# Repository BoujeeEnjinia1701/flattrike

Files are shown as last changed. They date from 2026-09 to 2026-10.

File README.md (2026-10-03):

# FlatTrike

     

**Area:** Mobility and Logistics · **TRL:** 3 of 9 (proof of concept on paper) · **Value-engineering target:** about $800 USD (estimated parts cost $736) · **Difficulty:** 3 of 5

Bolt-together cargo tricycle whose frame is cut from flat sheet steel by any laser or waterjet shop, uses standard bicycle parts, and ships flat.

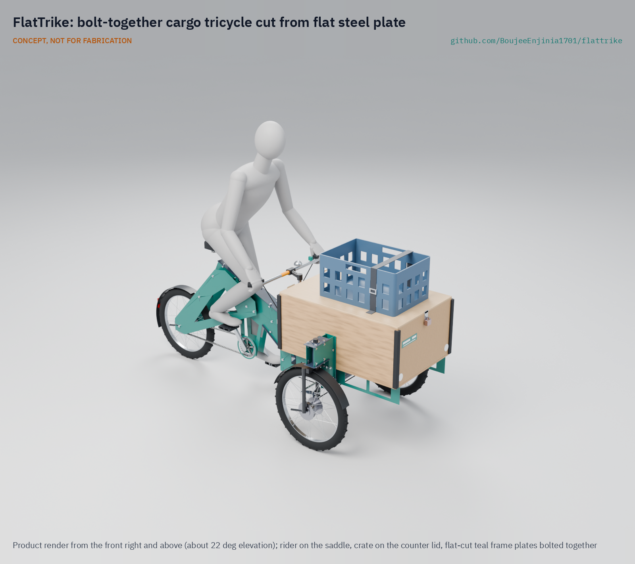
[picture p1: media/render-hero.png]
FlatTrike: bolt-together cargo tricycle cut from flat steel plate, product render


[Exploded render](media/render-exploded.png) · [Detail render](media/render-detail.png) · [Interactive 3D model](media/viewer.html) · [Concept blueprint (PDF)](media/concept-blueprint.pdf) · [General arrangement (PDF)](cad/drawings/FTK-DWG-001.pdf) · [Sizing note](docs/04-calcs/01-sizing.md) · [Prototype build plan](docs/05-build-plan.md) · [Design decisions](docs/06-design-decisions.md) · [Review note](docs/REVIEW.md)

## Concept rationale

Cargo tricycles fail their owners in two ways: cheap workshop builds flex, crack and weigh too much, and good imported ones cost too much to buy or repair. Precision is what separates them, and in a tubular frame precision comes from jigs and skilled welding. FlatTrike moves that precision into the cutting file. Every steel part is a flat 3 mm plate that any laser or waterjet shop can cut from open DXF files, tabs and slots make the plates locate one another, and bolts with all-metal locknuts replace welds. The moving parts (wheels, drum hubs, forks, headsets, chain and cranks) are standard bicycle parts sold in regional markets.

Keeping the design open and garage-buildable is the point, not a side effect. A frame that anyone can re-cut is a frame that a vendor in Pune or Nairobi can repair one plate at a time, at a local shop, without waiting for a proprietary spare. A prototype for about $800 in parts lets a cooperative, a university workshop or a single mechanic build and test one before anyone commits to a batch.

## Burning platform

About two billion people, more than 61 % of the world's employed population, work in the informal economy, rising to 85.8 % of employment in Africa ([ILO, 2018](https://www.ilo.org/resource/news/more-60-cent-world%E2%80%99s-employed-population-are-informal-economy)). Street vending and small-scale carrying are a large part of that work, and they run on human-powered vehicles. In India alone, the government's PM SVANidhi microcredit scheme had lent to more than 68 lakh (6.8 million) street vendors by July 2025 and is being extended to 2030 ([Press Information Bureau, 2025](https://www.pib.gov.in/PressReleasePage.aspx?PRID=2161157&reg=48&lang=2)).

The vehicles these workers use have barely changed. ITDP found that the traditional Indian cycle rickshaw weighs about 80 kg, has a single high gear, and has a wooden passenger structure that must be replaced every two to three years ([ITDP, 2006](https://itdp.org/2006/07/01/rickshaws-in-the-new-millennium/)). Every extra kilogram and every repair comes out of an income measured in trips per day, so a lighter, longer-lived and locally repairable cargo trike is worth more to these users than almost any other tool.

## Where it could be used

### By industry

| Industry | Use |
| --- | --- |
| Street vending and food retail | Mobile stall with a lockable box whose lid is a counter |
| Last-mile parcel and grocery delivery | Pedal or assisted delivery in dense districts and narrow lanes |
| Recycling and waste collection | Door-to-door collection of recyclables by informal and cooperative pickers |
| Water and gas cylinder distribution | Short, heavy delivery rounds from depot to households and shops |
| Agriculture and markets | Moving produce from farm gate or wholesale market to retail pitches |
| Municipal and campus services | Park, street-cleaning and maintenance crews carrying tools and supplies |

### By country or region

| Country or region | Why it matters there |
| --- | --- |
| India | More than 6.8 million street vendors have borrowed under PM SVANidhi ([PIB, 2025](https://www.pib.gov.in/PressReleasePage.aspx?PRID=2161157&reg=48&lang=2)); loading rickshaws and *thelas* are everywhere, and laser shops are common in industrial estates |
| Sub-Saharan Africa (for example Kenya and Nigeria) | 85.8 % of employment in Africa is informal ([ILO, 2018](https://www.ilo.org/resource/news/more-60-cent-world%E2%80%99s-employed-population-are-informal-economy)); goods move by handcart and bicycle on rough roads, where local repair matters most |
| Southeast and South Asia (for example Bangladesh and Indonesia) | 68.2 % of employment in Asia and the Pacific is informal ([ILO, 2018](https://www.ilo.org/resource/news/more-60-cent-world%E2%80%99s-employed-population-are-informal-economy)); cycle rickshaws and vending tricycles are a mainstay of city trade |
| The Americas (for example Mexico and Peru) | 40.0 % of employment in the Americas is informal ([ILO, 2018](https://www.ilo.org/resource/news/more-60-cent-world%E2%80%99s-employed-population-are-informal-economy)); a frame cut from open files suits small vendors and cooperatives in that informal economy |
| United States (New York City) | The city ran a commercial cargo bicycle pilot with delivery firms and published an evaluation ([NYC DOT](https://www.nyc.gov/html/dot/downloads/pdf/commercial-cargo-bicycle-pilot-evaluation-report.pdf)); an open, repairable frame suits small operators and community delivery schemes |

## What sparked the idea

The starting point was the OX, a flat-pack truck that Gordon Murray, the designer behind McLaren's road cars, developed for the Global Vehicle Trust, which the British philanthropist Torquil Norman founded to develop cost-effective transport for the developing world. TechCrunch reported in 2016 that six OX trucks pack into one shipping crate in flat-pack form and that a trained team of three can unpack and assemble one in about 12 hours ([TechCrunch, 2016](https://techcrunch.com/?p=1393387)). FlatTrike takes the same idea one scale down and one step further: instead of shipping a factory kit, it ships the files, so the flat parts can be cut in the city where the trike will work and re-cut there when one breaks.

## Problem

Street vendors and micro-logistics operators in emerging markets need durable cargo tricycles, but imported units are expensive and hard to repair, and cheap local workshop tricycles are heavy, flexible and short-lived.

## Concept

Bolt-together cargo tricycle whose frame is cut from flat sheet steel by any laser or waterjet shop, uses standard bicycle parts, and ships flat. The concept is a front loader: two 20 in front wheels, each steering in a standard bicycle fork linked by a tie rod (Ackermann steering), carry a fixed, lockable plywood box, and the rider sits over a standard 20 in rear wheel with a 3-speed drum brake hub. It is rated for 148 kg of cargo with a rider up to 80 kg, or 138 kg with a rider up to 90 kg, weighs 71.7 kg empty, turns in 5.64 m with a lock stop at each front wheel, and the pedal-only prototype costs $728 in parts. The TRL 3 calculations (FTK-CAL-001) show that unassisted hill climbing is not yet met, the production cost estimate (about $466) is over its $300 value-engineering target, and that making the design buildable added mass, so the cargo rating was trimmed by 2 kg to stay inside the 300 kg class (decided 2026-10-02); see the [design decisions register](docs/06-design-decisions.md) and the [review note](docs/REVIEW.md).

Full design precis: [docs/02-concept.md](docs/02-concept.md)

## Key components

- 37 laser-cut 3 mm steel plates: closed-box spine, rear stays, front bed, two knuckle posts and their steering lock stops, nested on one standard sheet
- Tab-and-slot joints and cut spacer washers with 97 M8 class 8.8 bolts and all-metal locknuts held in windows in the plates (no welding)
- Ackermann steering: central steering column in a 200 mm head tube, two 20 in straight-leg forks on their own 1 1/8 in headsets, each fitted turned round so the wheel trails its steering axis by 35 mm (decided 2026-10-03), tie rod and drag link
- 20 in wheels (3) with drum brakes; 3-speed hub at the rear
- Standard bicycle drivetrain, seat and handlebar
- Lockable plywood cargo box with a counter lid
- Optional electric assist on a SwapCell pack (route C; not in the prototype budget)

The working bill of materials is in [bom/bom.csv](bom/bom.csv).

## Building the prototype

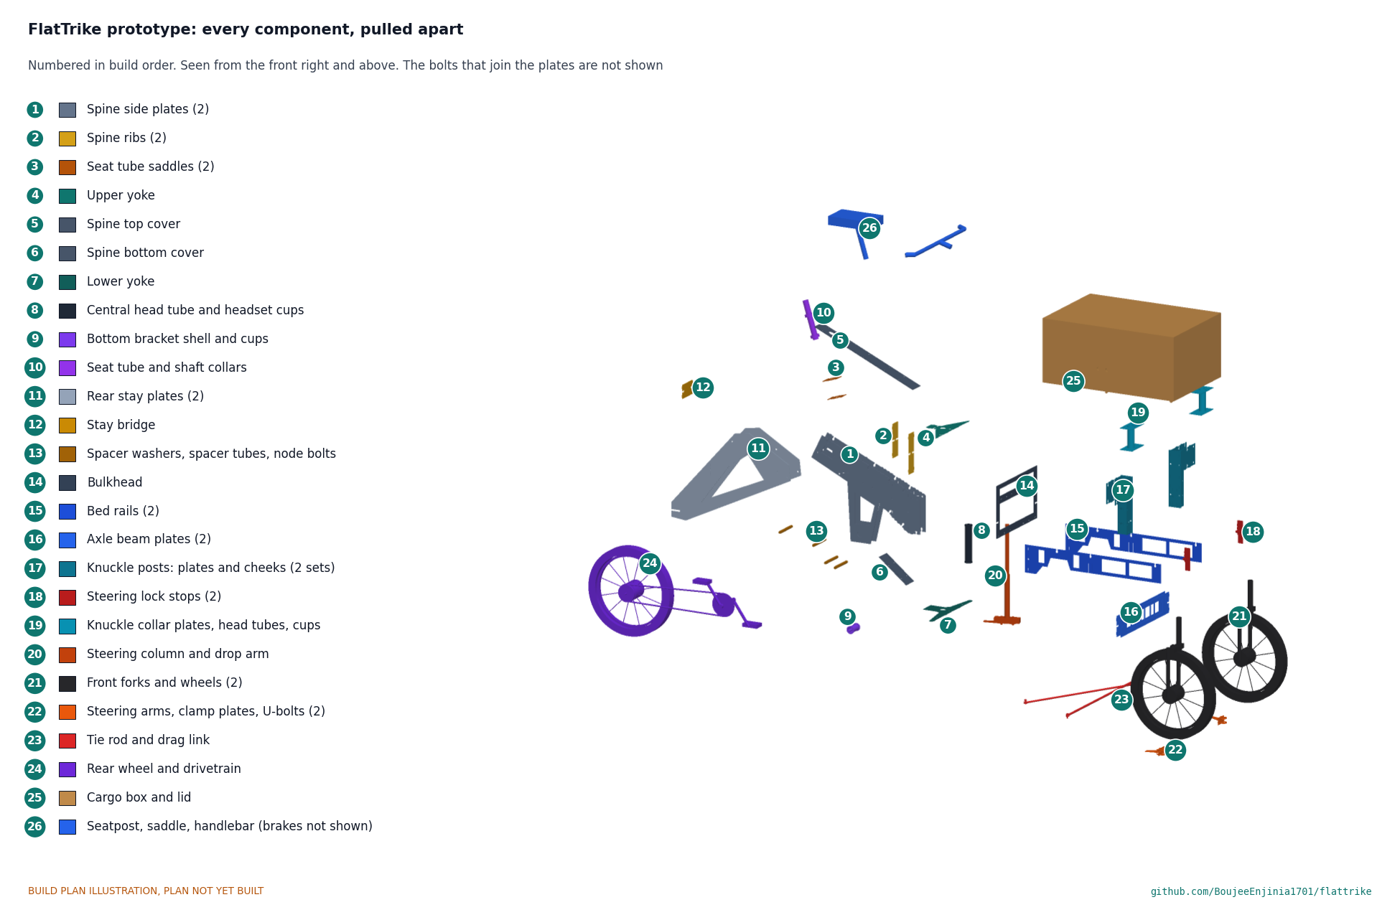
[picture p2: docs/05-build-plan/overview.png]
FlatTrike prototype: every component pulled apart and numbered in build order


The [prototype build plan](docs/05-build-plan.md) (FTK-BLD-001) shows, in pictures, how to make each of the 26 groups of parts and put them together in 21 steps; nothing has been built yet. Every frame part is a 3 mm plate cut by a laser or waterjet shop, joined by tabs in slots and M8 bolts whose locknuts sit in windows in the plates; the rest is bought bicycle parts, a cut-down fork for the steering column, three tube lengths and a plywood box. Writing the plan made the design buildable: the joints, stay bolts, dropouts, head tube clamping, steering linkage, steering arms and knuckle posts were redesigned (FTK-DDR-003, open for Amish's review), and the open decisions this raised are in the [design decisions register](docs/06-design-decisions.md). Every picture is drawn from the model, which checks that no two parts overlap, every part is fixed, and the steering turns lock to lock without touching the frame.

## Safety

> **Safety:** The frame's strength and fatigue life are unverified. Frames must be load-tested to twice the rated payload before use on public roads. Cut plate edges must be deburred, and the empty trike can tip in brisk turns, so riders must keep to 6 km/h in full-lock turns when empty. See the safety section of the [design precis](docs/02-concept.md).

## Repository layout

| Folder | Contents |
| --- | --- |
| `docs/` | Problem, concept, requirements, calculations, prototype build plan and design decisions |
| `cad/src/` | build123d Python source, the source of truth for all geometry |
| `cad/step/`, `cad/stl/` | Exported models for FreeCAD, other CAD tools and printing |
| `cad/drawings/` | 2D sketches and dimensioned drawings |
| `bom/` | Bill of materials |
| `electronics/` | KiCad schematics and PCB layouts |
| `firmware/` | Microcontroller code |
| `media/` | Renders, perspectives and photos |
| `build-log/` | Dated prototyping notes |

## Documentation

Controlled documents follow the portfolio [documentation standard](.kit/STANDARDS.md). Each carries a document ID (FTK-PRC-001 for the precis), a version and a revision history. Branded PDFs are built with `python .kit/render.py` and attached to GitHub Releases when a document is tagged, for example `FTK-PRC-001/v1.0`.

## Credits

Designed by Amish Chadha. See [CONTRIBUTORS.md](CONTRIBUTORS.md) for roles. To cite this design, use [CITATION.cff](CITATION.cff) (GitHub shows it as "Cite this repository").

AI assistance (Claude) was used to accelerate concept renders, prototype documentation and first-pass sizing calculations. Design direction and all decisions are Amish Chadha's, recorded in this repository's decision records (`docs/decisions/`).

## Licenses

- **Hardware** (CAD, drawings, BOM, electronics): [CERN-OHL-S v2](LICENSE)
- **Software** (firmware, scripts, notebooks): [MIT](LICENSE-SOFTWARE)

A project of the [Design Molecule](https://designmolecule.com) lab.

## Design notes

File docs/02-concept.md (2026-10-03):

---
doc_id: FTK-PRC-001
title: FlatTrike design precis
project: FlatTrike
doc_type: Design precis
version: "0.9"
status: Draft
date: '2026-10-03'
author: Amish Chadha
license: CERN-OHL-S-2.0
revisions:
- version: "0.1"
  date: '2026-09-24'
  author: Amish Chadha
  change: Initial scaffold
- version: "0.2"
  date: '2026-09-25'
  author: Amish Chadha
  change: Populate to TRL 2 (layout, components, first-order numbers, safety, media)
- version: "0.3"
  date: '2026-09-25'
  author: Amish Chadha
  change: TRL 3. Record decisions (FTK-DDR-001); closed-box spine, fork crown plates, wider stay strips, seat forward; numbers replaced with FTK-CAL-001 values
- version: "0.4"
  date: '2026-09-25'
  author: Amish Chadha
  change: Recommendations accepted by Amish (DDR-002)
- version: "0.5"
  date: '2026-10-01'
  author: Amish Chadha
  change: Design made constructable (FTK-DDR-003); key numbers from FTK-CAL-001 v0.3; build plan FTK-BLD-001
- version: "0.6"
  date: '2026-10-01'
  author: Amish Chadha
  change: Budget treated as a value-engineering target
- version: "0.7"
  date: '2026-10-02'
  author: Amish Chadha
  change: "Decisions of 2026-10-02: design for construction accepted; rating 148 and 138 kg, R8 72 kg, R14 60 min for knuckle post plates; steering lock stops and geometry study before the first ride; partner selection rule"
- version: "0.8"
  date: '2026-10-02'
  author: Amish Chadha
  change: "Key numbers from FTK-CAL-001 v0.6 with the 2026-10-02 decisions carried into the model: lock stops added (37 plates), 71.7 kg empty, 299.7 kg gross, turning circle 5.64 m through the built linkage, $728"
- version: "0.9"
  date: '2026-10-03'
  author: Amish Chadha
  change: "Knuckle forks turned round to trail (35 mm mechanical trail, no caster), decided by Amish 2026-10-03; key numbers from FTK-CAL-001 v0.7: wheelbase 1.415 m, turning circle 5.52 m, 71.6 kg empty, $736"
---

# FlatTrike design precis

FlatTrike is a front-loading cargo tricycle whose whole steel structure is a kit of 37 flat 3 mm plates, cut by any laser or waterjet shop from open files and bolted together through tabs, slots and spacer washers with no welding or bending. Two 20 in front wheels, each turning in a standard bicycle fork on its own headset, carry a fixed, lockable plywood cargo box; a tie rod links them in Ackermann geometry, and the rider sits over a standard 20 in rear wheel with a 3-speed drum brake hub. The TRL 3 calculations (FTK-CAL-001 v0.6, on the constructable design of FTK-DDR-003 with the decisions of 2026-10-02) show that the trike weighs 71.7 kg empty, carries 148 kg of cargo and an 80 kg rider (or 138 kg and a 90 kg rider) at 299.7 kg gross, resists tipping to 0.41 g loaded and 0.24 g with the rider only at any steering angle, turns in 5.64 m, cruises at 7.6 km/h on the flat on 110 W, nests on one standard sheet, packs into 0.31 m³ and costs an estimated $728 in prototype parts against the $800 value-engineering target (USD 72 under). One requirement is not met: a loaded 5 % hill needs 239 W at the pedals without assist (R13). The production estimate is about $466 against the $300 value-engineering target, USD 166 over (R18). The empty mass is only 0.3 kg under its 72 kg limit, and the final load label is set from the weighed trike. The [prototype build plan](05-build-plan.md) shows how every part is made and fitted.

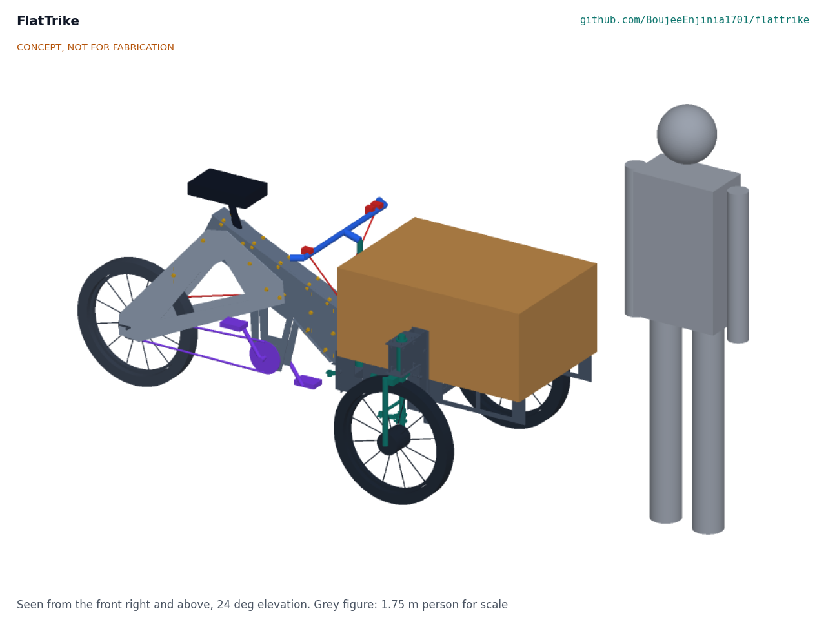
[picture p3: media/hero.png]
Hero render


*Figure 1. FlatTrike TRL 3 model with a 1.75 m person for scale. Every grey and dark steel part is a flat plate; wheels, forks, headsets, drivetrain, seat and bars are standard bicycle parts.*

## How it works

1. **Cut.** A laser or waterjet shop cuts 37 plates and 78 spacer washers from one 1,250 x 2,500 x 3 mm mild steel sheet using open DXF files, with the small plates nested in the windows of the large ones. Tabs, slots and bolt holes are cut in the same pass, so hole positions are as accurate as the cutter.
2. **Assemble.** The two spine side plates (item 1) are closed into a box beam by a top and a bottom cover plate held in slots, three ribs and cross-bolts. The box runs from the seat node to the head tube and has a drop lobe that clamps the bottom bracket shell. The rear stay plates (item 2) bolt to the outside of the spine through stacks of cut spacer washers at two nodes and carry the rear dropouts. The front bed (item 3) is a second bolted assembly: two yoke plates, a bulkhead, two rails, a twin-plate axle beam, and at each end of the beam a closed knuckle post of two transverse plates and two cheeks. No jig is needed because the plates locate one another.
3. **Fix the bed.** A 200 mm steel head tube (item 5) stands between two yoke plates at the front of the spine; each pressed headset cup passes through a yoke and clamps it to the tube's end. The yokes tab into the spine and into the bed's bulkhead, so the bed and box are fixed to the frame (FTK-DDR-003).
4. **Steer.** The handlebar (item 11) turns a steering column, a bought threaded fork cut off at its crown, in a standard 1 1/8 in threaded headset inside the head tube. A drop arm bolted under the crown, parallel to the left steering arm, drives a drag link to that arm, and a tie rod links both steering arms. Each front wheel sits in a bought 20 in fork that turns on its own headset in a 120 mm knuckle head tube, clamped above the tyre between two collar plates on the knuckle post. The fork's straight legs are offset 30 to 40 mm from its steerer, and it is fitted turned round so the wheel trails the steering axis by that offset (35 mm in the model): the tyre's side force then turns the steering back toward straight ahead. The steering arms clamp to the inboard fork legs below the knuckle posts and point at the rear axle centre, so the wheels follow Ackermann geometry.
5. **Ride.** A standard bottom bracket and cranks (item 8) drive the 20 in rear wheel (item 7) through a 32/24 chain and a 3-speed hub with a built-in drum brake. The chain runs at a 44 mm chain line in the gap between the right spine plate and the right stay plate.
6. **Stop and park.** Drum brakes in all three hubs (items 6 and 7) are sealed from rain and dust. A lever lock (item 12) holds the front pair when the trike is parked on a slope.
7. **Sell.** The plywood box (item 9) holds 151 L, locks, and has a hinged lid at 0.84 m that doubles as a counter. Its floor sits at 0.47 m so the steered tyres pass beneath it.

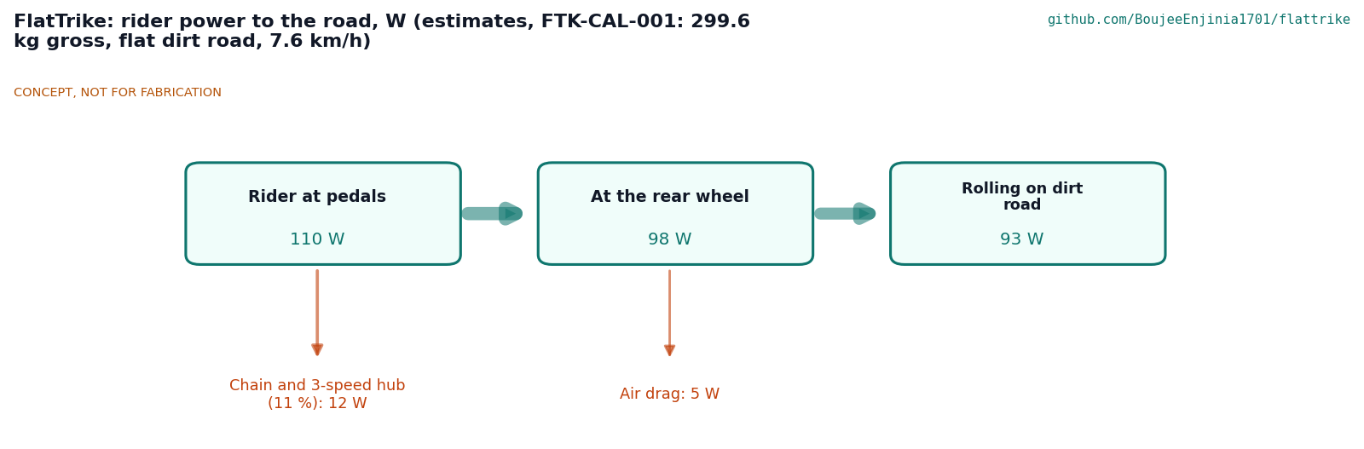
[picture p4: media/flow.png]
Rider power flow


*Figure 2. Where 110 W of rider power goes at 301.2 kg gross on a flat dirt road (FTK-CAL-001 section 4). All values are estimates.*

## Main components

Numbers match the exploded view (Figure 3) and `bom/bom.csv`. Dimensions are from `cad/src/model.py` and drawing FTK-DWG-001.

Table 1. Main components.

| # | Component | Choice | Notes |
| --- | --- | --- | --- |
| 1 | Spine plates and covers | Two 3 mm side plates about 681 x 585 mm, 60 mm apart, with top and bottom cover plates forming a closed 63 mm wide box, 150 to 215 mm deep | The open twin plates would see 569 MPa in torsion, the closed box 9 MPa; deepened at the front to clamp the 200 mm head tube |
| 2 | Rear stay plates (pair) | 3 mm plates about 745 x 555 mm, 120 mm apart for a 120 mm hub, upper strip at least 100 mm wide | Braced by a stay bridge; buckling safety factor 2.09 |
| 3 | Front bed and knuckle post plates | Lower and upper yoke (they clamp the head tube), bulkhead, two rails, twin 120 mm axle beam, and per side a closed knuckle post (two post plates, two cheeks) with two collar plates, all 3 mm | Fixed to the spine; the knuckle post column sees 40 MPa, the highest plate stress |
| 4 | Ribs, saddles, spacer washers and M8 bolts | Two spine ribs, a stay bridge, two seat tube saddles, 78 cut spacer washers, four spacer tubes; 95 M8 class 8.8 bolt sets with all-metal locknuts held in windows in the plates | Decided hardware (FTK-DDR-001 item 5); joints made physical in FTK-DDR-003 |
| 5 | Steering column, knuckles and linkage | Steering column in a 1 1/8 in threaded headset inside a bought 200 mm head tube; two knuckle headsets in 120 mm head tubes; two bought 20 in straight-leg forks (30 to 40 mm offset), fitted turned round to trail; drop arm, Ackermann steering arms and their clamp plates cut from plate; a cut-down fork as the column; U-bolts; drag link and tie rod with rod ends | Ackermann steering decided (FTK-DDR-002 item 13); 200 mm head tube decided (item 19); linkage made a parallelogram (FTK-DDR-003); forks turned to trail (2026-10-03) |
| 6 | Front wheels (2) | 20 x 2.125 in (ISO 406), 36-hole rims, 90 mm class front drum brake hubs for 100 mm fork dropouts | Each drum needs about 37 N·m |
| 7 | Rear wheel | 20 x 2.125 in with a 3-speed drum brake hub, 120 mm over locknuts, 24T sprocket | Development 1.60 to 2.84 m per crank turn |
| 8 | Drivetrain | Bought 68 mm bottom bracket shell clamped in the spine lobe, 170 mm cranks, 32T chainring, 1/8 in chain | Shell accepts a mid-drive later (assist route C) |
| 9 | Cargo box and lid | Exterior plywood, 820 x 560 x 360 mm, 12 mm floor, 9 mm walls and lid, floor at 0.47 m | 12.7 kg; 151 L; replaceable by a carpenter |
| 10 | Seat and seatpost | Sprung saddle on a 27.2 mm post on a 73° seat line through the bottom bracket | Saddle moved about 110 mm forward at TRL 3 for stability |
| 11 | Handlebar and stem | Steel riser bar on a stem clamped to the steering column | Carries the cornering-speed label |
| 12 | Brake levers, cables and parking latch | Two levers (front pair through a cable splitter, rear drum), lever lock on the front pair | |

Paint, fasteners for the box, mudguards, reflectors and a bell are in the BOM but not modelled. The optional assist kit (route C) is listed but outside the prototype budget.

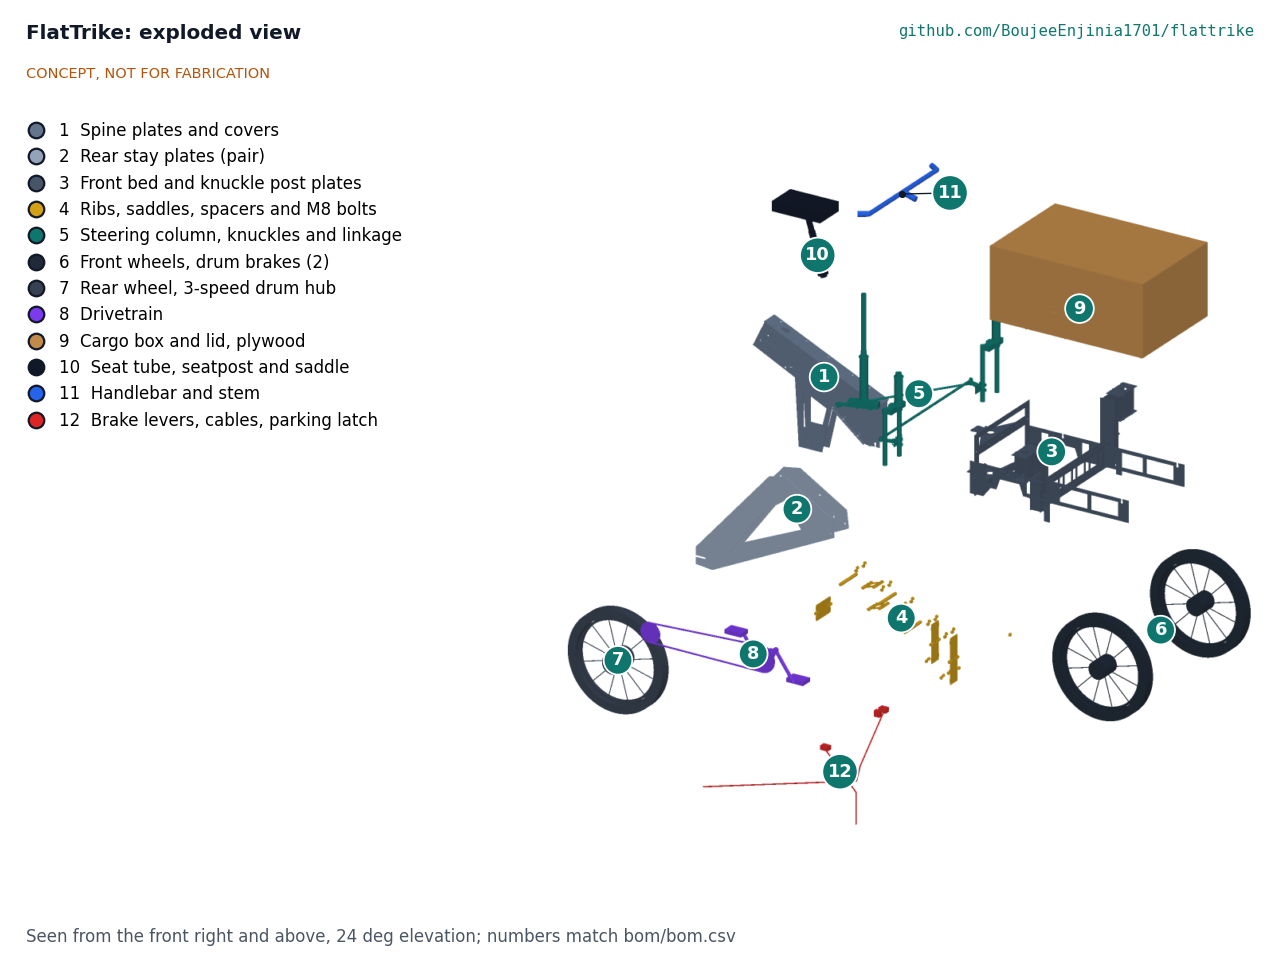
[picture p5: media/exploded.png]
Exploded view


*Figure 3. Exploded view with numbered callouts matching the BOM.*

## Key numbers (from FTK-CAL-001)

All values are first-principles estimates, printed by `docs/04-calcs/sizing.py`. The design load case is an 80 kg rider and 150 kg of cargo.

Table 2. Key numbers and requirement status.

| Quantity | Value | Requirement |
| --- | --- | --- |
| Length, width, height | 2.15 x 0.986 x 0.93 m; wheelbase 1.415 m (kingpins 1.45 m ahead of the rear axle, axles trailing 35 mm); track 0.84 m | R9 met |
| Turning circle, 40° inner lock at the lock stops, through the built linkage | 5.52 m (5.86 m upper bound) | R9 met |
| Plates | 37 plates, 1.31 m² net, 31.0 kg; 1,940 mm of a 2,500 mm sheet in a true-shape nest | R3 and R4 met |
| Empty mass | 71.6 kg (plates 43 %, box 18 %) | R8 (72 kg, restated 2026-10-02) met on paper |
| Gross mass | 299.6 kg (80 kg rider, 148 kg cargo; or 90 kg rider, 138 kg cargo) | R1 met on paper at the rating restated on 2026-10-02 |
| Flat-pack crate | about 1.38 x 0.62 x 0.36 m, 0.31 m³ | R6 met |
| Cruise on the flat at 110 W | 7.6 km/h | R12 met |
| 5 % grade at 4 km/h | 239 W at the pedals; 6.0 km/h with route C assist | **R13 not met unassisted** |
| Tipping threshold, any lock | 0.42 g loaded; 0.24 g rider only; label 6 km/h in full-lock turns when empty | R10 met |
| Highest plate stress (dynamic) | 40 MPa (knuckle post column); stay buckling safety factor 2.01 | R2 at risk |
| Braking and parking | About 37 N·m per drum; fade after about 1.9 km of 5 % descent | R11 at risk |
| Assembly | About 4.07 h for two people | R7 at risk (accepted 2026-10-02) |
| Repair | Spine side plate about 80 min (90 min allowed); knuckle post plate about 53 min (60 min allowed since 2026-10-02) | R14 met on paper |
| Pedal-only prototype parts | $736 | R15 within the value-engineering target ($800) |
| Production at 100 units | About $471 | **R18 over the value-engineering target by USD 171** (target $300) |

## TRL 3 design changes

The TRL 3 calculations found three failures in the TRL 2 concept and one steering problem. The first three were fixed in the model; the steering problem was fixed after Amish accepted the recommendations on 2026-09-25 (FTK-DDR-002).

- **Closed-box spine.** The single rear wheel cannot resist roll, so the rear frame and rider (116 kg) hang from the head tube joint, and a 0.5 g roll puts 512 N·m of torsion into the spine. Two separate 3 mm plates would see 569 MPa; with top and bottom cover plates the closed box sees 9 MPa.
- **Wider stay strips.** The upper stay strip is a compression member. The smaller TRL 3 window leaves a 100 mm strip with a buckling safety factor of 2.09, and only because the stay bridge braces it.
- **Ackermann steering with a fixed box (FTK-DDR-002 item 13).** Under box steering the outer wheel moved 334 mm inward at full lock and the empty trike could tip at 5.8 km/h. Each front wheel now turns in its own fork, so the track stays at 0.84 m at any lock and the rider-only threshold is 0.24 g or more throughout. The flat fork plates and crown plates of v0.3 are replaced by closed knuckle posts; the box is narrower (560 mm) and its floor higher (0.47 m) so the steered tyres pass under it.
- **Longer head tube (item 19).** The head tube grew from 150 to 200 mm, cutting the roll couple at the joint from 3.41 to 2.56 kN. With the bed fixed, the couple passes through the yokes rather than the headset bearings.
- **Design for construction (FTK-DDR-003, accepted by Amish on 2026-10-02).** Writing the build plan made every joint physical (tabs in slots, bolts into T-slots with captive locknuts), moved two stay bolts off a window, opened the rear dropouts, put the chain on the right, made the yokes the head tube clamps, made the steering linkage a parallelogram so it no longer locks on right turns, moved the steering arms below the knuckle posts and rebuilt the posts. It added 1.4 kg, so the cargo is now rated at 148 kg with a rider up to 80 kg and 138 kg with a rider up to 90 kg, and R8 at 72 kg (decided 2026-10-02); the final load label is set from the weighed trike.
- **Mass and stability (FTK-DDR-001 item 8, FTK-DDR-002 items 14 to 16).** Lightening windows, a 9 mm box, a seat 110 mm further forward and a 0.84 m track did not reach the original 55 kg and 0.30 g targets. Amish accepted relaxing R8 to 70 kg and the rider-only case of R10 to 0.22 g with a cornering-speed label, and rating the cargo at 140 kg for riders over 80 kg. Larger windows in the axle beam, rails and bulkhead kept the Ackermann version at 69.8 kg before the design-for-construction changes.

## Key design choices

Items marked decided were decided by Amish on 2026-09-25 (FTK-DDR-001 and FTK-DDR-002).

- **Layout.** Tadpole front loader. Decided.
- **Steering.** Ackermann steering with a fixed box for the first prototype. Decided (FTK-DDR-002 item 13), replacing box steering.
- **Joints.** Tabs and slots located by the cut, clamped by M8 class 8.8 bolts with all-metal prevailing-torque locknuts. Decided.
- **Plate material.** 3 mm S235JR or A36 class, primed and painted or powder coated. Decided.
- **Head tube and bottom bracket housings.** Bought steel sections clamped between plates. Decided. Central head tube 200 mm long (FTK-DDR-002 item 19).
- **Wheels and brakes.** 20 in on all three positions with drum brakes; 3-speed drum hub at the rear; bought 20 in forks at the front. Decided.
- **Electric assist.** None in the prototype. Decided. Route C, a 48 V mid-drive on a SwapCell pack, is the preferred route (decided). If built, it cites **SwapCell interface v0.3** items W (wake for hosts without CAN), C (charge while discharging) and V (latch class V1 for vehicles); the receiver meets latch class V1 and leaves the pack's back and lid faces open to air. The pack is priced once in the SwapCell repo and excluded from the FlatTrike budget.
- **Budget.** `budget_usd` stays at $800 for the pedal-only prototype, as a hypothetical value-engineering target, not a limit. Decided.
- **Targets.** R1 restated (148 kg cargo with a rider up to 80 kg, 138 kg with a rider up to 90 kg), R8 72 kg, R10 rider-only 0.22 g with a label, R14 90 min for the spine side plates and 60 min for the knuckle post plates. Decided (FTK-DDR-002; FTK-DDR-003, A1 and A2, 2026-10-02).
- **Production cost target.** $300 or less per trike at 100 units (R18), kept as a value-engineering target until the first partner supplies wholesale prices. Decided; the estimate is USD 166 over it.
- **Partner and city.** Decided 2026-10-02 as a selection rule: a city with dense goods delivery on narrow streets, a laser-cutting shop and a bicycle parts market. First candidate type to approach: a cycle-rickshaw or cargo-bike programme such as those ITDP has documented in South Asia; nothing is agreed.
- **Steering.** 1:1 parallelogram ratio kept; a lock stop at each knuckle post, met by its steering arm clamp plate at 40 degrees (now in the model, FTK-DWG-124). Decided 2026-10-02. The first-pass steering geometry study (FTK-CAL-001 section 5a) showed that the vertical head tubes give no caster and that a fork fitted with its offset forward gives negative trail.
- **Fork direction.** Each knuckle fork is a straight-leg fork with 30 to 40 mm offset, fitted turned round so the wheel trails: 35 mm of mechanical trail and no caster, measured on the model (FTK-CAL-001 section 5a). Decided by Amish 2026-10-03. The bed rails gained a tyre notch for the trailing tyres at full lock.

## Safety

> **Safety:** FlatTrike is a loaded vehicle of about 300 kg that shares the road with traffic, built from cut steel plate and exposed moving parts. Treat structural failure, tipping, braking, cut edges and pinch points as hazards at every stage. Nothing here is verified by test; TRL 4 is on hold by Amish's instruction.

- **Structural failure.** A bolted joint that loosens or slips, a stay strip that buckles, or a crack at a hole can let the frame collapse under load. Structural bolts need all-metal locknuts, a set torque and a check at every service. The frame must not be used on public roads until its strength and fatigue life are verified (R2), and routine overloading must be allowed for.
- **Tipping.** The empty trike tips at about 0.24 g (12 km/h on a 5 m radius, about 8 km/h in its tightest turn). A label on the bar tells riders to keep to 6 km/h in full-lock turns when empty. Keep heavy cargo low.
- **Steering joints.** The head tube clamps and yoke bolts carry the rear frame's roll moment (a 2.6 kN couple at 0.5 g), and the knuckle posts carry each front wheel. The tie rod and drag link rod ends must be secured with locknuts; a loose rod end means loss of steering. Check the clamps, bolts, headsets and rod ends at every service.
- **Braking and descents.** Drum brakes may fade after about 2 km of continuous loaded descent at 5 %. Descend slowly and in stages. The parking latch must hold the loaded trike on a slope, because a runaway trike in a market is a serious hazard.
- **Sharp edges.** Laser- and waterjet-cut edges and corners can be sharp and burred. Deburr every plate and radius every exposed corner before painting; protect hands during assembly.
- **Moving parts and pinch points.** The chain, chainring and spokes can catch clothing and fingers; fit a chain guard. The steered front wheels, tie rod and drag link move beneath the box and beside the rider's feet; keep hands and feet clear of the wheels and linkage. Steering lock stops at each knuckle post (40 degrees) must be fitted, and the steering geometry studied on paper, before the first ride.
- **Traffic visibility.** A slow, wide vehicle in mixed traffic needs reflectors, a bell and, for dusk use, lights.
- **Coatings.** Priming, painting and powder coating involve solvents and fine particles; use ventilation and masks.
- **Electric assist (route C only).** The lithium-ion pack needs its BMS, a fused output and safe charging, as set out in the SwapCell design. A pack that leaves its mount is a projectile with live contacts, so the receiver must meet latch class V1.

## Open questions

- Plate-and-joint FEA of the spine box, stays, knuckle posts, head tube clamps and bed against the EN 17860 load cases, once the standard is obtained.
- Steering feel with 35 mm of trail: pneumatic trail, shimmy and kickback are not quantified. The geometry in FTK-CAL-001 section 5a is repeated in the FEA session with the offset measured on the chosen fork, before the first ride (decided 2026-10-02).
- Drum brake torque, hub input torque, fork and headset ratings from the makers.
- DXF nesting by the cutting shop; the raster nest in FTK-CAL-001 leaves 310 mm spare but relies on cutting small parts from the windows of large ones.
- Partner, city, laser-shop quotes and wholesale prices for wheels, hubs and forks (R18 waits on these).

Concept media: [blueprint sheet](../media/concept-blueprint.pdf), [interactive 3D model](../media/viewer.html). General arrangement: `cad/drawings/FTK-DWG-001.pdf`.

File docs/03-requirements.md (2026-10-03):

---
doc_id: FTK-REQ-001
title: FlatTrike requirements
project: FlatTrike
doc_type: Requirements
version: "0.9"
status: Draft
date: '2026-10-03'
author: Amish Chadha
license: CERN-OHL-S-2.0
revisions:
- version: "0.1"
  date: '2026-09-24'
  author: Amish Chadha
  change: Initial scaffold
- version: "0.2"
  date: '2026-09-25'
  author: Amish Chadha
  change: First measurable requirements for TRL 2, with concept status
- version: "0.3"
  date: '2026-09-25'
  author: Amish Chadha
  change: TRL 3 status from FTK-CAL-001; R15 budget scope redefined; new R18 production cost target (FTK-DDR-001)
- version: "0.4"
  date: '2026-09-25'
  author: Amish Chadha
  change: Recommendations accepted by Amish (DDR-002)
- version: "0.5"
  date: '2026-10-01'
  author: Amish Chadha
  change: Status from FTK-CAL-001 v0.3 on the constructable design (FTK-DDR-003); R1, R8 and R14 not met, open decisions in FTK-DEC-001
- version: "0.6"
  date: '2026-10-01'
  author: Amish Chadha
  change: Budget treated as a value-engineering target
- version: "0.7"
  date: '2026-10-02'
  author: Amish Chadha
  change: "R1 rating restated (148 and 138 kg), R8 relaxed to 72 kg and R14 to 60 min for knuckle post plates on 2026-10-02 (FTK-DDR-003 A1 and A2); R1, R8 and R14 met on paper; R7 accepted at 4.04 h"
- version: "0.8"
  date: '2026-10-02'
  author: Amish Chadha
  change: "Status from FTK-CAL-001 v0.6 with the 2026-10-02 decisions carried into the model and calculations (steering lock stops, rating 148 and 138 kg, turning circle through the built linkage); no status change"
- version: "0.9"
  date: '2026-10-03'
  author: Amish Chadha
  change: "Status from FTK-CAL-001 v0.7 with the knuckle forks turned to trail (35 mm mechanical trail, decided by Amish 2026-10-03): wheelbase 1.415 m, turning circle 5.52 m, 71.6 kg empty, prototype $736, production about $471; no status change"
---

# FlatTrike requirements

These requirements are checked by calculation in FTK-CAL-001 v0.7 against the constructable TRL 3 model (FTK-DDR-003). Targets are still proposals until co-design sessions with users (see FTK-PRB-001). Amish's decisions of 2026-09-25 redefine what the prototype budget covers (R15) and add a production cost target (R18) (FTK-DDR-001), and then restate R1, R8, R10 and R14 and keep R18 as it is (FTK-DDR-002). On 2026-10-02 Amish accepted the design for construction and restated R1 (148 kg of cargo with a rider up to 80 kg, 138 kg with a rider up to 90 kg), R8 (72 kg) and R14 (60 min for a knuckle post plate) (FTK-DDR-003, A1 and A2; FTK-DEC-001), so these three are met on paper. One requirement is **not met** at TRL 3: R13 without assist. R18 (production cost) is **over its value-engineering target** by USD 171. The final load label is set from the weighed trike.

The **design load case** is an 80 kg rider and 148 kg of cargo in the box on a trike of 71.6 kg: 299.6 kg gross, on a flat dry road unless stated. The upper case is a 90 kg rider with 138 kg of cargo, also 299.6 kg. FTK-CAL-001 v0.7 computes every figure at this rating.

Table 1. FlatTrike requirements and TRL 3 status (FTK-CAL-001 v0.7).

| ID | Requirement | Target | Verification | TRL 3 status |
| --- | --- | --- | --- | --- |
| R1 | Carry the rated load | 148 kg of cargo in the box with a rider up to 80 kg, or 138 kg with a rider up to 90 kg; gross mass 300 kg or less, within the EN 17860 cargo cycle class (restated, FTK-DDR-002; rating restated 2026-10-02, FTK-DDR-003 A1; final label set from the weighed trike) | Mass budget (FTK-CAL-001 section 3) | Met on paper: 299.6 kg in both cases at the 2026-10-02 rating (FTK-DEC-001) |
| R2 | Frame strength | Frame survives a static proof load of twice the rated payload with no permanent set, and a fatigue load case representative of commercial use under EN 17860 | Hand calculation (section 6); FEA next; proof test later | At risk: stresses 41 MPa or less and fatigue ranges below the limit, but stay buckling has a safety factor of only 2.16, the knuckle post columns reach 41 MPa and the tab-and-slot joints need FEA |
| R3 | No welding | Every steel part is flat 3 mm plate cut from a DXF file by laser or waterjet; no bending, welding or brazing; joints bolted with locknuts | Model review | Met: 37 plates and 78 spacer washers, all flat, joined by tabs, slots and bolts; head tubes, seat tube and spacer tubes are bought sections cut to length |
| R4 | One standard sheet | All steel frame parts nest on one 1,250 x 2,500 x 3 mm sheet (4 x 8 ft class) | Nesting check (section 2) | Met: 1,985 mm of sheet used by a true-shape nest; bounding rectangles alone would need 2,669 mm |
| R5 | Standard bicycle parts | Wheels (20 in, ISO 406), hubs, brakes, forks (20 in), headsets (1 1/8 in), bottom bracket, cranks, chain (1/8 in), seatpost (27.2 mm) and saddle are standard sizes sold in regional markets | Parts availability survey with the partner | Met by design, with the head tubes and bottom bracket shell as bought steel sections (decided); survey pending |
| R6 | Ships flat | Complete kit, wheels included, packs into 0.4 m³ or less with no piece longer than 1.0 m | Packing estimate | Met: about 0.31 m³; longest piece 0.85 m |
| R7 | Assembled with hand tools | Two people assemble the kit in 4 h or less with spanners to 17 mm, hex keys, cone spanners and a screwdriver; no jig, because the plates locate each other with tabs and slots | Work-content estimate; later timed build | At risk: about 4.07 h for 97 bolt sets, the headsets and the steering linkage, about 4 minutes over; accepted 2026-10-02, to be timed at TRL 4 |
| R8 | Light enough to ride and push | Empty mass 72 kg or less including the box (relaxed from 55 kg, FTK-DDR-002, and from 70 kg on 2026-10-02, FTK-DDR-003 A1); still lighter than the 80 kg traditional rickshaw documented by ITDP | Mass budget | Met on paper: 71.6 kg with the steering lock stops and the forks turned to trail, 0.4 kg under (FTK-DEC-001) |
| R9 | Fits market lanes | Overall width 1.0 m or less; length 2.2 m or less; turning circle 6 m or less | Model and steering geometry | Met: 0.986 m wide, 2.15 m long, 5.52 m turning circle through the built linkage at the 40° inner lock set by the lock stops (5.86 m upper bound); the trailing contact patches shorten the wheelbase to 1.415 m |
| R10 | Resist tipping in turns | Lateral acceleration at the tipping point 0.30 g or more loaded, and 0.22 g or more with the rider only together with a cornering-speed label (rider-only case relaxed, FTK-DDR-002) | Stability calculation (section 5); later tilt-table test | Met: 0.42 g loaded and 0.24 g rider only at any lock (lowest straight ahead; the trailing outer contact moves out as the wheels turn); label reads 6 km/h for full-lock turns when empty |
| R11 | Stop and park safely | Stop from 15 km/h in 6 m or less at gross mass on a dry road; drum brakes on all three wheels; a parking brake that holds the loaded trike on a 10 % grade | Braking calculation (section 7); later field test | At risk: each drum needs about 37 N·m (rating not yet confirmed); fade after about 1.9 km of loaded 5 % descent |
| R12 | Pedal on the flat | Cruise at 7 km/h or more at gross mass on a flat dirt road with 110 W at the pedals | Power calculation | Met: 7.6 km/h |
| R13 | Climb local hills | Climb a 5 % grade for 100 m at 4 km/h or more at gross mass without the rider dismounting | Power and gearing calculation | **Not met without assist:** 239 W needed at the pedals. Met with assist route C (6.0 km/h), which is not in the prototype |
| R14 | Repairable locally | Any single plate or standard part replaced in 30 min or less with hand tools, except a spine side plate in 90 min or less (FTK-DDR-002) and a knuckle post plate in 60 min or less (FTK-DDR-003 A2, 2026-10-02); open DXF files let any laser shop re-cut one plate | Bolt-count estimate; later repair trial | Met on paper: knuckle post plate about 53 min (both collar plates and the headset cups come off), within 60 min; spine side plate about 80 min, within 90 min |
| R15 | Affordable prototype | Parts for the pedal-only prototype cost at or below the value-engineering target of $800 (`project.yaml` `budget_usd`, a hypothetical control target). The optional assist kit and any SwapCell pack are outside this budget; a SwapCell pack is priced once in the SwapCell repo | Priced BOM (`bom/bom.csv`) | **Within the value-engineering target:** $736 against $800 (USD 64 under) |
| R16 | Last in commercial service | Frame life of 5 years or more in daily outdoor commercial use, against 2 to 3 years for traditional wooden rickshaw frames (ITDP) | Corrosion and fatigue review; later field trial | Not verifiable at TRL 3: unprotected steel could lose up to 0.42 mm in 5 years; depends on coating and sealed joints |
| R17 | Work as a stall | Lockable box of 150 L or more; box lid usable as a counter at 0.75 to 0.95 m height | Model check | Met: 151 L inside; lid at 0.84 m |
| R18 | Competitive in production | Production cost at or below the value-engineering target of $300 per trike at 100 units (decided by Amish, 2026-09-25; kept, FTK-DDR-002) | Cost estimate (section 9); later partner quotes | **Over the value-engineering target by USD 171:** about $471, over two thirds of it bought bicycle parts; wholesale prices wait on a partner |

## Assumptions

- Rolling resistance coefficient about 0.015 on a mix of worn asphalt and packed dirt; drag area about 0.9 m² for an upright rider behind a cargo box; air density 1.2 kg/m³.
- The rider sustains about 110 W at the pedals for an hour; short efforts can reach 200 W or more.
- Drivetrain efficiency (chain and 3-speed hub) about 89 %.
- Plate is 3 mm hot-rolled mild steel (S235JR or ASTM A36 class), density 7,850 kg/m³.
- Plywood is 9 to 12 mm exterior grade, about 700 kg/m³.
- Volume prices (R18) assume one full sheet at $1.0/kg, cutting at $0.30/m and bought parts at 65 % of prototype retail; no quotes yet.
- The 300 kg gross limit follows the EN 17860 class for single and multi-track cargo cycles; the standard's detailed test loads have not yet been checked against this design.

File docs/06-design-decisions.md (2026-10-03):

---
doc_id: FTK-DEC-001
title: FlatTrike design decisions register
project: FlatTrike
doc_type: Design decisions register
version: "0.5"
status: Draft
date: '2026-10-03'
author: Amish Chadha
license: CERN-OHL-S-2.0
revisions:
- version: "0.1"
  date: '2026-10-01'
  author: Amish Chadha
  change: Register opened with the build plan; open items from the review note, the decision records and the build work
- version: "0.2"
  date: '2026-10-01'
  author: Amish Chadha
  change: Budget treated as a value-engineering target
- version: "0.3"
  date: '2026-10-02'
  author: Amish Chadha
  change: "Amish approved the recommendations for all open decisions 1 to 10 on 2026-10-02 (FTK-DDR-003 accepted; rating 148 and 138 kg, R8 72 kg, R14 60 min for knuckle post plates; steering stops at the knuckle posts); moved to decisions made"
- version: "0.4"
  date: '2026-10-02'
  author: Amish Chadha
  change: "Value engineering restated after the 2026-10-02 decisions were carried into the design (lock stops in BOM line 3; FTK-CAL-001 v0.6)"
- version: "0.5"
  date: '2026-10-03'
  author: Amish Chadha
  change: "Fork direction decided by Amish 2026-10-03 (knuckle forks turned to trail, 35 mm mechanical trail); knuckle fork added to the items to confirm; value engineering restated (BOM line 5 $100; FTK-CAL-001 v0.7)"
---

# FlatTrike design decisions register

Every design decision still to be made, and every decision made, in one place. Each decision is argued in full in its decision record under `docs/decisions/`; this register is the index Amish works from. The build plan (`docs/05-build-plan.md`) describes the design as it stands and does not list open decisions.

## Open decisions

None. All open decisions were decided on 2026-10-02.

## To confirm when parts are bought

*Table 1. Items to confirm when parts are bought.*

| # | What to confirm | Why it matters | Source |
| --- | --- | --- | --- |
| 1a | The two knuckle forks: 20 in steel, 100 mm dropouts, threaded 1 1/8 in steerer, straight legs parallel to the steerer with 30 to 40 mm offset (measure it); 22 mm legs | Fitted turned round, the offset is the trail (30 to 40 mm); a bent-leg fork would put the steering arm clamp on the bend | FTK-CAL-001 section 5a; decided 2026-10-03 |
| 1 | The steering column fork: threaded 1 1/8 in steel fork with a separate forged crown (roadster type) solid enough to drill two 9 mm holes 32 mm either side of the steerer; steerer at least 250 mm | The drop arm bolts under the crown | FTK-DDR-003, P8 |
| 2 | A quill stem with about 350 mm of quill for a 1 1/8 in threaded steerer, 70 mm or more inside the steerer | It sets the handlebar height of 850 mm | FTK-DDR-003, P8 |
| 3 | Front fork leg diameter (22 mm assumed) and M6 U-bolts that fit it; the U-bolts' grip holds the steering arm under a firm push on the bar | The steering arms are held by friction on the leg | FTK-DDR-003, P10 |
| 4 | Front drum hub body 90 mm across or less where the steering arm clamp plate passes over it | The clamp plates clear a 90 mm hub by about 6 mm | FTK-DDR-003, P10 |
| 5 | Rod ends for M8 bolts with at least ±10° misalignment | The drag link slopes about 6° | FTK-DDR-003, P9 |
| 6 | Headset cups' spigots long enough to pass a 3 mm plate and still seat 10 mm in the head tube | The cups clamp the yokes and collar plates | FTK-DDR-003, P7 and P11 |
| 7 | A cartridge bottom bracket for a 68 mm shell that works with 66 mm between the cup flanges (60 mm shell and two 3 mm plates) | The cups clamp the spine plates | FTK-DDR-003, P5 |
| 8 | Hub axles long enough for 3 mm dropouts plus non-turn washers and nuts; front drum reaction arms that fit the forks | The dropouts are thinner than a bicycle frame's | FTK-DDR-003, P3 |
| 9 | Drum brake torque of about 37 N·m per wheel, and the 3-speed hub's input torque limit for 32/24 gearing | R11 and the hub's life | FTK-CAL-001; BOM lines 6 and 7 |
| 10 | The laser or waterjet shop holds slot widths to about 0.1 mm (3.4 mm slots for 3 mm tabs) | Tabs must enter by hand and not rattle | FTK-DDR-003, P1 |
| 11 | Seat tube 31.8 x 2.3 mm whose bore takes a 27.2 mm seatpost | The seatpost clamps in it | FTK-DDR-003, P6 |

## Value engineering

Value-engineering target: USD 800 (a hypothetical control target, not a limit). Estimated cost of the constructable design: USD 736 (USD 64 under the target). Main cost drivers and savings worth trying:

- The largest prototype lines are the two front wheels with drum brakes (USD 110), the rear wheel with 3-speed drum hub (USD 95), the steering column, knuckles and linkage (USD 100) and the front bed and knuckle post plates with the steering lock stops (USD 89). The construction changes (FTK-DDR-003) added USD 15 (USD 709 to USD 724), the two lock stops and their bolts USD 4 (USD 724 to USD 728), and the straight-leg knuckle forks fitted turned to trail USD 8 (USD 728 to USD 736).
- The optional route C assist kit (USD 300, without the SwapCell pack) is outside the prototype target.
- Production target: USD 300 per trike at 100 units (R18) against an estimate of about USD 471, USD 171 over the target. Bought bicycle parts are USD 329 of it at 65 % of retail, with USD 74 of steel (one full sheet), USD 17 of cutting, the plywood box at 60 % and USD 15 of assembly labour.
- Savings worth trying: wholesale prices for wheels, hubs and forks once the first partner supplies them (FTK-DDR-002, item 18), and the one-sheet nest that already keeps the steel and cutting low.

## Decisions made

*Table 2. Decisions made.*

| Date | Decision | Decided by | Record |
| --- | --- | --- | --- |
| 2026-09-25 | TRL 2 review items 1 to 9, 11 and 12: tadpole front loader; box steering first with Ackermann assessed; no assist in the prototype, route C (SwapCell) preferred; 3 mm S235 or A36 plate, painted; M8 8.8 bolts with all-metal locknuts; bought head tube and bottom bracket sections; 20 in wheels with drum brakes and a 3-speed rear hub; design changes before relaxing R8 and R10; $300 production target (R18); `budget_usd` $800 for the pedal-only prototype; problem line reworded | Amish: "proceed with all of your recommendations across all batches. Make sure we don't proceed to TRL 4 on any of them." | FTK-DDR-001 |
| 2026-09-25 | Cross-cutting: SwapCell interface v0.3 items W, C and V for assist route C; a SwapCell pack is priced once in the SwapCell repo; partners are picked per area later | Amish, same instruction | FTK-DDR-001 |
| 2026-09-25 | Items 13 to 19: Ackermann steering with a fixed box; R8 70 kg; R10 rider-only 0.22 g with a cornering-speed label; 140 kg cargo for riders over 80 kg; R14 90 min for a spine side plate; keep the $300 target; 200 mm head tube | Amish: "i accept all your recommendations, go with them across all repos." | FTK-DDR-002 |
| 2026-09-25 | TRL 4 on hold; the repo stays at TRL 3 | Amish's instruction | `project.yaml`; review note |
| 2026-09-26 | FlatTrike in the first batch of product renders | Amish | Review note, 2026-09-26 |
| 2026-09-30 | Write the illustrated build plan and make the design physically buildable as it is drawn; keep open decisions out of the build plan, in this register | Amish: "If you are realising that the design cannot be built as per concept - fix the design assumptions to match and be physically feasible as you draw the illustrations." and "don't log outstanding decisions in this build plan - that is not the place for it. that should be in a separate design document logged and named as such" | FTK-DDR-003 (Draft, open for review); this register |
| 2026-10-02 | Design for construction accepted: the changes P1 to P15 of FTK-DDR-003 and their knock-on changes, as made | Amish: "i approve your recommendations for all 555 open decisions." | FTK-DDR-003, Tables 1 and 2 |
| 2026-10-02 | Rated load (option c): rated now at 148 kg of cargo with a rider up to 80 kg, or 138 kg with a rider up to 90 kg, and R8 relaxed to 72 kg; the lightening windows are tried in the FEA session, and the final load label is set from the weighed trike | Amish: "i approve your recommendations for all 555 open decisions." | FTK-DDR-003, A1 |
| 2026-10-02 | Repair time: 60 min allowed for a knuckle post plate (R14) | Amish: "i approve your recommendations for all 555 open decisions." | FTK-DDR-003, A2 |
| 2026-10-02 | Assembly time: about 4.04 h accepted against R7's 4 h, timed at TRL 4 | Amish: "i approve your recommendations for all 555 open decisions." | FTK-DDR-003, A3 |
| 2026-10-02 | Steering lock stops (option b, changed from a): a stop at each knuckle post that its steering arm clamp plate meets at 40 degrees, fitted before the first ride | Amish: "i approve your recommendations for all 555 open decisions." | Build plan work; this register |
| 2026-10-02 | Steering ratio: the 1:1 parallelogram linkage is kept | Amish: "i approve your recommendations for all 555 open decisions." | FTK-DDR-003, P9 |
| 2026-10-02 | Steering geometry: caster, trail, kingpin inclination, scrub radius and self-centring are studied on paper in the FEA session, with the bought fork's rake as input, before the first ride | Amish: "i approve your recommendations for all 555 open decisions." | FTK-PRC-001, open questions |
| 2026-10-02 | First partner and city: kept open under the portfolio rule, chosen as a city with dense goods delivery on narrow streets, a laser-cutting shop and a bicycle parts market. First candidate type to approach: a cycle-rickshaw or cargo-bike programme such as those the Institute for Transportation and Development Policy (ITDP) has documented in South Asia | Amish: "i approve your recommendations for all 555 open decisions." | FTK-DDR-002, item 10 |
| 2026-10-02 | Render frame colour: teal and graphite for the renders only; the coating is chosen with the partner | Amish: "i approve your recommendations for all 555 open decisions." | Review note 2026-09-26, item 1 |
| 2026-10-02 | Appearance model details (bent fork legs, round tyre section, box hardware positions, flat-cut chain guard, brake cable runs) accepted as appearance only | Amish: "i approve your recommendations for all 555 open decisions." | Review note 2026-09-26, items 4 to 8 |
| 2026-10-03 | Fork direction (steering geometry before the first ride): each knuckle fork is a straight-leg fork with 30 to 40 mm offset, fitted turned round so the wheel trails its vertical steering axis; 35 mm of mechanical trail, no caster; bed rails notched and knuckle post lip trimmed for the swinging tyre and crown; wheelbase 1.415 m, turning circle 5.52 m | Amish: "FlatTrike - i accept your design recommendation, proceed and execute the solution for fork direction or caster" | FTK-CAL-001 section 5a; review note 2026-10-03 |

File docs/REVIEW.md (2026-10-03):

# Review note: FlatTrike

## Session 2026-09-25: /populate to a strong TRL 2

### What was done

- `docs/01-problem.md` (FTK-PRB-001 v0.2): problem with sourced figures (street vendor numbers, local rickshaw prices and weight, imported trike price), users, operating environment, constraints, out of scope, prior work with inline sources, open questions and a co-design checklist.
- `docs/03-requirements.md` (FTK-REQ-001 v0.2): 17 measurable requirements (R1 to R17) with targets, a design load case, assumptions and a concept status column that marks the requirements not met.
- `docs/02-concept.md` (FTK-PRC-001 v0.2): how it works, numbered components, first-order numbers (size, mass, riding power, hills, stability, structure, braking, cost), proposed design choices with options, safety section, open questions.
- `cad/src/concept_media.py`: massing model of a tadpole front-loading trike. Every steel part is a flat 3 mm plate (spine pair, rear stay pair, front bed plates) with a BOM number; standard bicycle parts for wheels, drivetrain, seat, bars and brakes.
- `media/`: `hero.png` (1.75 m scale figure), `concept-blueprint.png`, `.pdf` and `.svg`, `exploded.png` with callouts 1 to 12 matching the BOM, `flow.png` (rider power to the road, estimates), `model.glb` and `viewer.html`. No cutaway, because the inside of the design does not carry the idea; the side and top views on the blueprint show the plate layout.
- `bom/bom.csv`: 15 lines with indicative USD prices, items 1 to 12 matching the exploded view; `bom/bom-notes.md` updated to say what the base cost includes.
- `README.md`: hero image and links line before "## Problem"; concept paragraph, key components and safety note updated to match.
- `docs/pdf/`: branded PDFs of the three controlled documents.

### Key results (estimates, to be checked at TRL 3)

| Quantity | Estimate | Requirement |
| --- | --- | --- |
| Overall size | about 2.11 x 0.96 x 0.94 m; wheelbase 1.45 m; track 0.80 m | R9 met |
| Rated load, gross mass | 150 kg cargo plus 80 kg rider; about 298 kg gross | R1 met, no margin against 300 kg |
| Empty mass | about 68 kg (plates about 30 kg, box about 16 kg) | **R8 (55 kg) not met** |
| Steel plate area | about 1.5 m², against a 3.1 m² standard sheet | R4 likely met |
| Flat pack | about 0.36 m³ | R6 likely met |
| Flat cruise at 110 W | about 7.6 km/h | R12 met |
| 5 % hill at 4 km/h | about 240 W at the pedals needed | **R13 not met unassisted** |
| Tipping threshold | about 0.38 g loaded; about 0.18 g with rider only | **R10 not met empty** |
| Plate bending stress | about 20 to 26 MPa, against about 235 MPa yield | R2 unverified (fatigue and joint slip) |
| Base prototype parts (pedal only) | about $640 | R15 met |
| With optional electric assist | about $1,040 | **R15 not met** |

Requirements not met or at risk:

- **R8 (empty mass) not met:** about 68 kg against 55 kg.
- **R10 (stability) not met with no cargo:** about 0.18 g, a turn on a 5 m radius at about 11 km/h. Box steering makes this worse at full lock.
- **R13 (hill climb) not met without assist:** a loaded 5 % grade needs about twice sustained rider output.
- **R15 (cost) not met if the assist option is included:** about $1,040 against $800.
- **R1 at the limit:** gross mass is within about 2 kg of the 300 kg class limit with an 80 kg rider, and over it with a 90 kg rider.
- **R2, R7, R11, R14 and R16 unverified:** frame fatigue and joint stiffness, assembly time, braking and fade, repair time and service life need TRL 3 work.

### Proposed, awaiting Amish

1. **Layout.** A: tadpole front loader (modelled). B: delta rear loader (*thela* layout; needs a non-standard live rear axle). C: delta front loader. Recommendation: A.
2. **Steering.** A: box steering on one kingpin (modelled; simplest). B: Ackermann steering with a fixed box (better stability, about $40 more). Recommendation: A for the first prototype, B assessed at TRL 3 because of R10.
3. **Electric assist.** A: none in the base, with a bottom bracket housing that accepts a mid-drive later. B: generic 36 V mid-drive with its own pack (about $400). C: 48 V mid-drive on a SwapCell pack, shared with the portfolio (kit about $260 plus pack about $370). Recommendation: A for the prototype, C as the preferred assist route. This is the only place SwapCell is proposed.
4. **Plate material:** 3 mm S235JR or A36 class steel, painted or powder coated, rather than S355 or stainless. Recommendation as stated.
5. **Joint hardware:** M8 class 8.8 bolts with all-metal locknuts rather than nylon-insert nuts.
6. **Head tube and bottom bracket housings:** bought steel sections clamped between plates (recommended), bolt-in bearing housings, or parts salvaged from a donor frame.
7. **Wheels:** 20 in on all three positions with drum brakes; 3-speed hub at the rear.
8. **Revised targets or design changes for R8 and R10.** Options: lighten the plates and box, widen the track (breaks R9), move the seat forward and lower, or relax the targets. Recommendation: try design changes first at TRL 3.
9. **Production cost target.** Local workshop tricycles sell for about ₹10,000 to ₹25,000 (about $120 to $300) in India, so the $800 prototype budget says little about competitiveness. Recommendation: set a production target, for example $300 or less per trike at 100 units, before TRL 3.
10. **First partner and city** for co-design and laser shop quotes.
11. **Budget.** The pedal-only base (about $640) is within `budget_usd` ($800), which is unchanged. No budget change is proposed unless option 3B or 3C is chosen for the prototype, which would need about $1,040.

`project.yaml` pitch and problem are unchanged. The research supports them for imported and branded trikes, but in South Asia the main competitor is the cheap local workshop tricycle, so the case rests on durability, mass, gears and repair rather than price alone. Consider adding that nuance to the problem line (proposed, awaiting Amish).

### Safety concerns

- Structural failure of bolted plate joints (loosening, slip, fatigue cracks at holes) under a 300 kg vehicle, with routine overloading in commercial use. No public-road use before strength and fatigue are verified.
- Tipping of the empty trike in brisk turns, made worse by box steering.
- Drum brake fade on long loaded descents; the parking latch must hold on slopes.
- Sharp and burred laser-cut edges; every plate must be deburred and corners radiused.
- Pinch point between the pivoting front bed and the spine near the rider's feet; exposed chain and spokes.
- If assist is chosen: lithium-ion pack hazards as set out in the SwapCell design.

### Problems and notes

- The kit renderer's hidden-line projector failed on two coaxial tori (the front tyres), so tyres are modelled as flat rings. This does not affect proportions.
- The legacy placeholder `cad/src/model.py` is untouched; the parametric model is TRL 3 work.
- The IndiaMART price range is a marketplace snapshot, not a survey, and should be checked with a partner.
- No cutaway was produced (see above).

### Recommended next step

Review this note and the media, then decide items 1 to 3 and 9. If approved, run `/advance-trl3` to check the plate frame's stiffness and fatigue against EN 17860 load cases, work on the mass and stability shortfalls, design the head tube and bottom bracket clamps, and produce the parametric model, nesting study and drawing sheet.

## Session 2026-09-25: TRL 3

Amish's instruction for this session (2026-09-25): "proceed with all of your recommendations across all batches. Make sure we don't proceed to TRL 4 on any of them." Every TRL 2 item with a recommendation is now recorded as decided; items without one stay open. **TRL 4 is on hold by Amish's instruction.**

### What was done

- `docs/decisions/0001-trl2-review-decisions.md` (FTK-DDR-001 v0.1): decisions 1 to 9, 11 and 12, the cross-cutting SwapCell and partner rules, and open items 10 and 13 to 19.
- `docs/04-calcs/01-sizing.md` (FTK-CAL-001 v0.1) with `docs/04-calcs/sizing.py` and `docs/04-calcs/results.csv`: geometry and nesting, mass and centre of mass, power and gearing, steering and stability (box and Ackermann), structure (torsion, crowns, stay buckling, headset, joints, fatigue), braking and fade, assembly and repair time, corrosion, cost. The script reads the model and the BOM, so the numbers stay in step.
- `cad/src/model.py`: parametric build123d model (key dimensions in `PARAMS`), exporting `cad/step/flattrike-{assembly,frame,front-bed}.step` and matching STL files, and printing the plate schedule. TRL 3 changes: closed-box spine with top and bottom covers, vertical fork crown plates, smaller stay windows, seat on a 73° line about 110 mm further forward, 0.84 m track, 120 mm rear hub spacing, box 360 mm high with 9 mm walls, cut spacer washers instead of tubes.
- `cad/src/sheets.py` and `cad/drawings/FTK-DWG-001.svg`, `.pdf` (and `.png`): general arrangement at Rev P1, "CONCEPT, NOT FOR FABRICATION" and "PRELIMINARY, NOT FOR FABRICATION". The concept sheet keeps FTK-DWG-010, so DWG-001 was the next free number.
- `bom/bom.csv`: 15 lines, every line priced with a supplier type; base $647 against $800. `bom/bom-notes.md` updated.
- `cad/src/concept_media.py` now builds its parts from `model.py`; `media/` refreshed (hero, blueprint, exploded, flow, model.glb, viewer). Every image was checked. In the blueprint isometric the kit's scale figure stands just beyond the box and its outline overlaps the box corner; this is kit placement and reads correctly.
- `docs/01-problem.md`, `docs/02-concept.md`, `docs/03-requirements.md` moved to v0.3 (decisions, R15 redefined, new R18, checked numbers). `project.yaml` (trl 3, trl_target 3, evidence, problem line) and `README.md` updated.

### Requirement status (FTK-CAL-001; 8 met, 6 not met, 3 at risk, 1 not verifiable)

| ID | Status | Value |
| --- | --- | --- |
| R1 | **Not met** with a 90 kg rider | 307.5 kg gross (297.5 kg with 80 kg) |
| R8 | **Not met** | 67.5 kg empty against 55 kg |
| R10 | **Not met** with no cargo | 0.24 g straight, 0.11 g at full box-steering lock (tips at 5.8 km/h); 0.43 g loaded |
| R13 | **Not met** unassisted | 238 W at the pedals needed; 6.0 km/h with route C assist |
| R14 | **Not met** for the spine side plates | about 78 min (42 bolts) |
| R18 | **Not met** | about $414 at 100 units against $300 |
| R2 | At risk | stresses 45 MPa or less; stay buckling SF 2.06; headset 3.34 kN per bearing |
| R7 | At risk | about 3.6 h for two people |
| R11 | At risk | about 37 N·m per drum needed; fade after about 1.9 km of 5 % descent |
| R16 | Not verifiable at TRL 3 | coating-dependent |
| R3, R4, R5, R6, R9, R12, R15, R17 | Met | 27 flat plates; 2,486 of 2,500 mm sheet; standard parts; 0.39 m³; 0.986 m wide and 5.67 m turning circle; 7.6 km/h; $647; 184 L and 0.77 m counter |

Numbers in the TRL 2 documents that changed: empty mass 68 to 67.5 kg (box was underestimated by about 3 kg; windows saved about 6 kg; covers and crowns added), 5 % climb 240 to 238 W, drum power on a 5 % descent 0.4 to 0.27 kW (rolling resistance was left out), rider-only tipping 0.18 to 0.24 g (seat moved), box volume 190 to 184 L, lid 0.79 to 0.77 m, turning circle 5.8 to 5.67 m.

Structural findings: the TRL 2 open twin-plate spine would see 556 MPa in torsion and the flat fork bridges 619 MPa; both are fixed in the TRL 3 model (9 and 23 MPa). Buckling of the stay strips and the headset roll load now govern.

### Decisions recorded (FTK-DDR-001)

Decided by Amish, 2026-09-25, go with recommendation: tadpole front loader; box steering for the first prototype with Ackermann assessed at TRL 3; no assist in the prototype, route C (SwapCell) preferred; 3 mm S235 or A36 painted; M8 8.8 with all-metal locknuts; bought head tube and bottom bracket sections clamped between plates; 20 in wheels with drums and a 3-speed rear hub; design changes tried before relaxing R8 and R10; production target $300 at 100 units (new R18); `budget_usd` kept at $800 for the pedal-only prototype (R15 redefined); problem line reworded. Cross-cutting: route C cites SwapCell interface v0.3 items W, C and V (latch class V1); the SwapCell pack is priced once and excluded; partners are picked per area later.

### Still awaiting Amish

- Item 10: first partner organization and city (no recommendation; picked per area later).
- Item 13: switch the first prototype to Ackermann steering (recommended) because of full-lock tipping.
- Item 14: R8, recommend relaxing to 70 kg including the box.
- Item 15: R10 rider-only case, recommend 0.22 g with Ackermann and a cornering-speed label.
- Item 16: R1, recommend 140 kg rated cargo for riders over 80 kg.
- Item 17: R14, recommend 90 min for the spine side plates only.
- Item 18: R18, recommend keeping $300 and getting wholesale part prices first.
- Item 19: headset under roll load, recommend a longer head tube or taper roller bearings.

### Citations

The TRL 2 note listed no unchecked citations. The EN 17860 summary (ACT Lab) was re-fetched and supports the 300 kg multi-track class and doubled pedaling-force cycles for commercial use; the numeric test loads are not public and were not read. The IndiaMART price range is still a marketplace snapshot to check with a partner.

### Safety concerns

- Empty trike tips at about 5.8 km/h at full box-steering lock (0.11 g) and at 0.24 g straight.
- The headset carries the rear frame's roll moment (about 3.3 kN per bearing at 0.5 g).
- Stay strips are compression members with a buckling safety factor of about 2; removing the stay bridge would halve it.
- Drum fade after about 2 km of loaded 5 % descent; drum and parking torque ratings unconfirmed.
- Bolted joint slip and fretting, cut edges, pinch points at the steering bed, and lithium-ion hazards if route C is built.

### Other notes

- No TRL 4 material exists in this repo (`build-log/README.md` is the scaffold header only; `electronics/` and `firmware/` are empty). Nothing was added to them.
- The bounding-rectangle nest fits the sheet with only 14 mm to spare; true-shape DXF nesting is still needed.

### Recommended next step

Amish decides items 13 to 19 in FTK-DDR-001, then a TRL 3 refinement session on paper: a plate-and-joint FEA of the spine box, stays and bed, Ackermann steering geometry if chosen, headset sizing, true-shape nesting from DXF, and supplier data for hubs, drums and prices. **TRL 4 is on hold by Amish's instruction.** For the record only, TRL 4 would need: the EN 17860 load cases, DXF files and a chosen partner and laser shop, one frame cut and assembled, lab test reports (TST, `environment: lab`) for the proof load, stay buckling, joint slip, tipping threshold and braking, build-log entries, and a build budget decision.

## Session 2026-09-25: recommendations accepted

Amish wrote on 2026-09-25: "i accept all your recommendations, go with them across all repos." Every open item with a recommendation (items 13 to 19) is now **Decided by Amish, 2026-09-25: go with recommendation**, recorded in `docs/decisions/0002-recommendations-accepted.md` (FTK-DDR-002 v0.1) and marked in FTK-DDR-001 v0.2. Item 10 has no recommendation and stays open. **TRL 4 remains on hold by Amish's instruction**; `trl` and `trl_target` stay at 3.

### Decisions applied and what changed

| # | Decision | Before | After |
| --- | --- | --- | --- |
| 13 | Ackermann steering with a fixed box for the first prototype | Box steering on one kingpin; rider-only tipping 0.11 g (5.8 km/h) at full lock | Fixed bed; two 20 in forks on knuckle headsets in closed knuckle posts, tie rod, drag link; rider-only 0.24 g at any lock; 27 plates to 34; box 795 x 700 to 820 x 560 mm, floor 400 to 470 mm, 184 to 151 L, lid 0.77 to 0.84 m; turning circle 5.67 to 5.95 m; BOM item 5 $25 to $85 |
| 14 | R8 relaxed to 70 kg with the box | Target 55 kg; 67.5 kg (not met) | Target 70 kg; 69.8 kg (met, 0.2 kg margin) after larger windows in the axle beam, rails and bulkhead |
| 15 | R10 rider-only case 0.22 g with Ackermann and a cornering-speed label | Target 0.30 g; 0.24 g straight (not met) | Target 0.22 g; 0.24 g (met); label "6 km/h in full-lock turns when empty" added to BOM item 14; loaded 0.43 to 0.41 g |
| 16 | Cargo 140 kg for riders over 80 kg | 307.5 kg gross with a 90 kg rider (not met) | 299.8 kg with 90 kg and 140 kg, and with 80 kg and 150 kg (met, 0.2 kg margin) |
| 17 | R14 allows 90 min for the spine side plates only | 78 min against 30 min (not met) | 78 min against 90 min (met); knuckle post plate 27 min |
| 18 | Keep the $300 production target; wholesale prices from the first partner first | $414 estimate | Target unchanged; estimate $456 with the steering parts (not met); prices wait on item 10 |
| 19 | Longer head tube | 150 mm; 3.34 kN per headset bearing in roll | 200 mm; roll couple 2.56 kN, carried by the collar and yoke clamps of the fixed bed, not the bearings |

Other changes: prototype parts $647 to $709 (`budget_usd` stays $800; R15 met); empty mass 67.5 to 69.8 kg; assembly 3.6 to 4.0 h; bolt sets 112 to 116; 5 % climb 238 to 240 W; crate 0.39 to 0.30 m³. FTK-CAL-001 v0.2 adds a true-shape raster nest, because 34 plates no longer fit by bounding rectangles (2,805 mm); the true-shape nest uses 2,190 of 2,500 mm. Files: `cad/src/model.py` (STEP and STL re-exported), `cad/src/sheets.py` and FTK-DWG-001 Rev P2, `cad/src/concept_media.py` and `media/`, `docs/04-calcs/sizing.py`, `results.csv` and `01-sizing.md` (v0.2), `bom/bom.csv`, `bom/bom-notes.md`, FTK-PRB-001, FTK-PRC-001 and FTK-REQ-001 (v0.4), `project.yaml` (evidence list) and `README.md`.

README: added "Concept rationale", "Burning platform", "Where it could be used" and "What sparked the idea" before "## Problem". The inspiration point is the Global Vehicle Trust OX flat-pack truck by Gordon Murray Design (CarsGuide, 2016). All generated files were re-rendered with designmolecule.com.

### Requirement status (FTK-CAL-001 v0.2; 12 met, 2 not met, 3 at risk, 1 not verifiable)

| ID | Status | Value |
| --- | --- | --- |
| R13 | **Not met** unassisted | 240 W at the pedals needed; 6.0 km/h with route C assist |
| R18 | **Not met** | about $456 at 100 units against $300 |
| R2 | At risk | stresses 47 MPa or less (knuckle post column); stay buckling SF 2.09 |
| R7 | At risk | about 4.0 h for two people, at the limit |
| R11 | At risk | about 37 N·m per drum needed; fade after about 1.9 km of 5 % descent |
| R16 | Not verifiable at TRL 3 | coating-dependent |
| R1, R8 | Met, 0.2 kg margin | 299.8 kg gross; 69.8 kg empty |
| R3, R4, R5, R6, R9, R10, R12, R14, R15, R17 | Met | 34 flat plates; 2,190 mm of sheet; standard parts; 0.30 m³; 0.986 m wide, 5.95 m turning circle; 0.41 and 0.24 g; 7.6 km/h; 78 min; $709; 151 L and 0.84 m |

### Still awaiting Amish

- Item 10: first partner organization and city (no recommendation; partners are picked per area later). Item 18's wholesale prices wait on it.

### Cross-repo actions

None. Assist route C still cites SwapCell interface v0.3 items W, C and V, unchanged.

### Safety concerns

- The empty trike still tips at 0.24 g; the bar label (6 km/h in full-lock turns when empty) is the control.
- The knuckle post columns (47 MPa, 155 MPa without their cheek plates) and the head tube clamps now carry the highest loads; the tie rod and drag link rod ends are single points of failure for steering.
- Mass has only 0.2 kg of margin against the 300 kg class; any added part reduces the rated cargo.
- Earlier concerns (stay buckling, drum fade, cut edges, lithium-ion hazards on route C) are unchanged.

### Recommended next step

A TRL 3 refinement on paper: plate-and-joint FEA of the knuckle posts, head tube clamps, spine box and stays; a steering geometry study (caster, trail, kingpin inclination, self-centering with bought forks); and a mass review to recover margin under 70 kg. **TRL 4 is on hold by Amish's instruction.** For the record only, TRL 4 would need a partner and laser shop, DXF files, one frame cut and assembled, and lab tests of the proof load, knuckle posts, tipping threshold and braking.

## Session 2026-09-26: sources strengthened

Amish asked for the weaker sources to be fixed. README sections "Concept rationale" to "What sparked the idea" were checked link by link; every kept link was fetched and supports its claim.

| Where | Old source | New source |
| --- | --- | --- |
| What sparked the idea (Global Vehicle Trust OX) | CarsGuide, 2016 (trade press, alone) | TechCrunch, 27 September 2016, "The OX is a flat-pack truck for the developing world". The claim now states only what that report supports: six per shipping crate flat-packed, a trained team of three, about 12 hours. The 40 ft container, spanner and Allen key details were removed because they could not be verified from a primary or reputable source. |
| By country or region, row "Latin America (for example Mexico and Peru)" | None (uncited claim about *triciclo* vendors) | Rewritten as "The Americas (for example Mexico and Peru)", citing ILO, 2018: 40.0 % of employment in the Americas is informal |
| Burning platform, ITDP rickshaw sentence | ITDP, 2006 (kept) | Same source; wording corrected to match it: a single high gear, and a wooden passenger structure replaced every two to three years |

Kept and re-verified: ILO, 2018 (two billion, 61 %, 85.8 % Africa, 68.2 % Asia and the Pacific); Press Information Bureau, 2025 (more than 68 lakh vendors, lending extended to 31 March 2030); NYC DOT commercial cargo bicycle pilot evaluation report. The Gordon Murray Design press page could not be reached from this session, so no primary OX page is cited. `INSPIRATIONS.md` line for flattrike updated to the new source. No budget change. `docs/01-problem.md` does not cite CarsGuide, so it is unchanged; its IndiaMART price listing (a marketplace, cited alone) is outside this session's scope and is left for a later pass.

## Session 2026-09-26: product appearance model and photoreal renders

Amish chose this repo for the first batch of product renders on 2026-09-26. This session adds an appearance model for photoreal renders; it changes no dimension, interface, decision or number in the design.

### What was added

- `cad/src/product_model.py`: `product_parts()` returns 107 named parts (colour, material, BOM line, group and explode offset), plus `TITLE` and three `RENDER_VIEWS` (hero, exploded and a close "detail" of the core frame and drivetrain). It imports `PARAMS`, the plate profiles (`SPINE`, `STAY` and the bed profiles), `plate()` and the helpers from `model.py`, so every main dimension and interface is unchanged. It adds:
  - powder-coated flat 3 mm plates with laser-cut corner radii, the left and right plates as separate parts so the exploded view shows the flat-cut kit;
  - rib tabs showing through their slots, zinc M8 bolt heads, washers and locknuts at the spine, stay, bed and knuckle-post joints, and grooved cut spacer-washer stacks;
  - tyres with tread, 36-spoke wheels, drum brake hubs with brake arms, the 3-speed rear hub and its click box, axle nuts;
  - a toothed 32T chainring and 24T sprocket, a roller chain, a flat-cut chain guard ring, tapered cranks and platform pedals with pins;
  - headset cups, filleted fork crowns, rod ends on the drag link and tie rod;
  - a sprung saddle, rubber grips, brake levers, the parking latch, a bell and the cornering-speed label on the bar;
  - the plywood box with panel seams, counter lid, hinges, hasp and padlock, rubber corner bumpers, a name plate and reflectors; mudguards;
  - context: a produce crate strapped to the lid and the shared clay mannequin (1.76 m, pose "ride"), fitted from its landmarks so it sits on the saddle, its feet meet the pedals at the model's 55 degree crank angle and its hands meet the grips.
- `README.md`: the hero image now points to `media/render-hero.png`, and the links line starts with the exploded render. The render files are produced later by the orchestrator.

### Where the appearance model differs from model.py (each Proposed, awaiting Amish)

1. **Frame colour.** The spine side plates, stays, bed rails and knuckle posts are shown in the kit accent teal (#0F766E) powder coat, with graphite covers, ribs, yokes, bulkhead, axle beams and collar plates. BOM item 13 leaves the finish open. Recommendation: accept teal and graphite as the render finish only; choose the production coating with the partner.
2. **Chain side.** `model.py` puts the chain line at +44 mm on +Y, which its own axes call the left, while the precis (step 5) says the chain runs on the right. The appearance model keeps `model.py`, so the drivetrain is on the left and the detail view is taken from the front left. Recommendation: confirm right-hand drive (standard bicycle parts expect it) and flip the sign in `model.py` in the next CAD session.
3. **Yoke-to-collar bolts.** Four bolts are drawn just ahead of the head tube; BOM item 4 counts eight and `model.py` does not place them. Recommendation: accept as representative; place all eight in the plate-and-joint FEA session.
4. **Fork legs.** The bought forks are drawn with a small forward bend (18 mm) and a filleted crown; `model.py` shows straight legs. Dropout, crown height and width are unchanged. Recommendation: accept as appearance only; rake and trail belong to the steering geometry study.
5. **Tyre section.** Tyres are round in section (torus) with tread blocks instead of the flat-sided massing ring. Outer radius (254 mm) and width (54 mm) are unchanged. Recommendation: accept.
6. **Box hardware positions.** Hinges on the rear edge, hasp and padlock centred on the front face, corner bumpers and a name plate are placed for the render; BOM items 9 and 14 do not fix their positions. Recommendation: accept for renders; revisit with the lid-as-counter use once a partner is chosen.
7. **Chain guard.** BOM item 8 lists a chain guard without a form; it is shown as a flat-cut ring guard outside the chainring. Recommendation: accept, since it can be cut from the same sheet offcuts.
8. **Brake cable runs.** The long cable runs sit in the "context" group so they appear in the assembled hero but not across the exploded view. Recommendation: accept.

### TRL status

This is an appearance model only: no tolerances, no fabrication detail, no PCB or cut files. `trl` stays 3 and TRL 4 remains on hold by Amish's instruction.

## Session 2026-09-27: kit 1.5.0 and image quality

- Kit 1.5.0 synced: STANDARDS v1.5 (sections 12 to 15: product renders, storefront images and image quality, public release, authorship and signing), `.kit/cards.py`, `.kit/image_qc.py`, `.kit/release_gate.py`, issue templates, and the `/render-product` and `/release` commands. `CLAUDE.md` now matches `.kit/CLAUDE.md`.
- Every `media/render-*.png` recaptioned from its original render with the new layout: the title, concept label and repository sit in a band above the render and the view note in a band below it, each line wrapped to the image width, so no text overlaps other text or the render or runs off the image. `media/card.png` and `media/social-preview.png` regenerated with the same rules.
- `python .kit/image_qc.py` and `python .kit/release_gate.py` pass. trl stays 3.

## Session 2026-10-01: build plan and design for construction (kit 1.7.0)

Following Amish's 2026-09-30 approval of the build plan format, with outstanding decisions kept in a separate register, and his instruction: "If you are realising that the design cannot be built as per concept - fix the design assumptions to match and be physically feasible as you draw the illustrations."

### What was done

- Kit 1.7.0 installed (`.kit/`, `.claude/commands/`); `CLAUDE.md` now matches `.kit/CLAUDE.md`.
- `cad/src/model.py` rewritten so every physical piece is its own solid: 35 cut plates with their tabs, slots, bolt holes and T-slots, the bought parts and 95 bolt sets (163 pieces). `python cad/src/model.py --check` runs the constructability checks: every tab, slot, hole and T-slot lies on solid plate; no two pieces overlap; every piece touches the assembly; and the wheels, forks, arms, drag link, tie rod and steering column sweep from full left to full right lock without touching the fixed structure. **All pass.** `build_parts()` still returns the twelve BOM groups for the calculations, concept media and drawing.
- `docs/decisions/0003-design-for-construction.md` (FTK-DDR-003, Draft): every change below, with the reason, made under Amish's 2026-09-30 instruction to make the design physically buildable; open for his review.
- `cad/src/build_plan_media.py`: overview, making sketches FTK-DWG-101 to 123 (23 sheets), 14 joint close-ups and 21 assembly step pictures, all drawn from the model.
- `docs/05-build-plan.md` (FTK-BLD-001 v0.1) and `docs/06-design-decisions.md` (FTK-DEC-001 v0.1).
- `docs/04-calcs/sizing.py` now reads bolt, tab and node counts from the model; FTK-CAL-001 v0.3, FTK-REQ-001 v0.5 and FTK-PRC-001 v0.5 carry the new numbers. `bom/bom.csv` lines 1, 3, 4, 5, 8, 9, 10 and 11 respecified ($724, was $709). FTK-DWG-001 Rev P3; concept media regenerated (concept sheet Rev P2). `project.yaml`: `design_state: constructable`, evidence list. README: links line and "Building the prototype".

### Design changes made for construction (FTK-DDR-003)

1. Every plate joint made physical: tabs in slots carry the load; M8 bolts go through the face plate into a T-slot in the edge plate, with the all-metal locknut held in a window. Spine covers widened to 90 mm so their bolt holes have plate round them; ten tabs per edge in the closed box.
2. Two stay-to-spine bolts moved off the spine's rear window; a spacer tube inside the spine on each of the four bolts.
3. Rear dropouts opened to the stays' rear edge (they were closed holes).
4. Chain moved to the right-hand side (standard parts are right-hand drive).
5. Bottom bracket shell 60 mm, between the spine plates; its cups clamp the plates.
6. Bought seat tube in two cut saddles with shaft collars; the rib at 380 mm removed; oval hole in the top cover.
7. Yokes made the head tube clamps (cups through them); upper yoke between the spine plates, lower yoke under a new level edge of the spine; the two head tube collar plates removed.
8. Steering column from a bought forged-crown fork with its legs cut off; drop arm bolted under the crown.
9. Steering linkage made a parallelogram (120 mm drop arm parallel to the left steering arm): the concept's linkage locked after about 10° of right turn. The handlebar now turns as far as the left wheel.
10. Steering arms moved below the knuckle posts (321 mm up) on clamp plates held to the inboard fork legs by two U-bolts; knuckle posts and axle beams start at 350 mm (were 290 mm); axle beams 120 mm deep.
11. Knuckle posts rebuilt: post plates 25 mm either side of the head tube so the cup flange loads them directly (the concept's collar plates were bent by the wheel load); inner cheek a face plate; outer cheek inset; post plates step clear of the fork crown's sweep.
12. Bulkhead window split, bulkhead bottom raised 6 mm; rails extended 20 mm behind the bulkhead, rear lower edge raised, first window reduced.
13. Rails and axle beams joined by halving joints; beam windows moved off the crossings.
14. Box fixed by six bolts into the rails and two into the bulkhead on 9 mm washer stacks (box 9 mm further forward); counterbores in the box sides for the knuckle post bolt heads.
15. Front hubs 100 mm (they were drawn 106 mm in 100 mm forks).

### Key results (FTK-CAL-001 v0.3)

- Empty mass 71.2 kg (was 69.8 kg); gross 301.2 kg with the rated loads. **R1 and R8 are not met by 1.2 kg.**
- **R14 not met** for a knuckle post plate (about 53 min against 30 min); spine side plate about 80 min (met).
- R7 at risk: about 4.04 h for two people (95 bolt sets, was 116).
- R13 not met as before (241 W); R18 over its value-engineering target as before (about $465 against $300, USD 165 over). R2 and R11 at risk; R16 not verifiable.
- Plates 35 (was 34); true-shape nest 1,940 mm of 2,500 mm; stay buckling safety factor 2.01; knuckle post column 40 MPa (was 47 MPa); axle beam 36 MPa; tab bearing 87 MPa; tyre to knuckle post 36 mm at full lock (was 19 mm).
- Prototype parts $724 against the $800 value-engineering target (unchanged; USD 76 under).

### Proposed, awaiting Amish (all in `docs/06-design-decisions.md`)

1. Review and accept the design-for-construction changes (FTK-DDR-003).
2. Rated load and mass: cargo 148 kg (80 kg rider) and 138 kg (90 kg rider) and R8 72 kg now, and look for 1.2 kg at the FEA session (recommended).
3. R14: allow 60 min for knuckle post plates (recommended).
4. R7: accept 4.04 h and time it at TRL 4 (recommended).
5. Steering lock stops: two stop bolts on the lower yoke (recommended).
6. Steering ratio: keep 1:1 (recommended).
7. Steering geometry study; first partner (item 10); render colour and appearance model details from the 2026-09-26 session.

### Stale files (made on Amish's Mac, not regenerated here)

`media/render-hero.png`, `media/render-exploded.png`, `media/render-detail.png`, `media/card.png`, `media/social-preview.png` and the appearance model `cad/src/product_model.py` still show the concept: the chain on the left, the head tube collar plates, steering arms at 400 mm, wider knuckle posts with windows, narrow spine covers and no visible tabs. They need updating with `/render-product`. The appearance deviations of 2026-09-26 item 2 (chain side) and item 3 (yoke-to-collar bolts) are now settled by FTK-DDR-003.

### Safety concerns

- The steering arms are held by U-bolt friction on the fork legs; their grip must be checked before any ride (build plan safety stops).
- The tab-and-slot joints carry the frame loads by bearing; they need FEA and a proof load (R2).
- Nothing stops the steering at 40° until stop bolts are added (open decision 5).
- Earlier concerns stand: rider-only tipping at 0.24 g, stay buckling, drum fade, cut edges.

### Recommended next step

Amish reviews FTK-DDR-003 and the register. Then a TRL 3 refinement on paper: plate-and-joint FEA with the tab joints, the mass review for decision 2, the steering stops and a steering geometry study; and new renders on the Mac. **TRL 4 remains on hold by Amish's instruction.**

## Session 2026-10-02: open decisions decided

On 2026-10-02 Amish approved the recommendations for every open decision: "i approve your recommendations for all 555 open decisions." The 10 open decisions of the design decisions register are now in its Decisions made table, dated 2026-10-02.

FTK-DDR-003 (design for construction) is accepted, with A1 to A3 decided as recommended. The cargo rating is restated at 148 kg with a rider up to 80 kg and 138 kg with a rider up to 90 kg, R8 at 72 kg and R14 at 60 min for a knuckle post plate, so R1, R8 and R14 are met on paper; R13 stays not met without assist and R18 over its value-engineering target. The calculation script still computes at the old rating until it is updated (follow-up 1). Item 5 was decided on a changed recommendation: steering lock stops at the knuckle posts rather than through-bolts in the lower yoke; the stop and the steering geometry study are now in safety stop S6 of the build plan.

### Documents changed

- `docs/06-design-decisions.md` (FTK-DEC-001 v0.3)
- `docs/decisions/0003-design-for-construction.md` (FTK-DDR-003 v0.3)
- `docs/01-problem.md` (FTK-PRB-001 v0.5)
- `docs/02-concept.md` (FTK-PRC-001 v0.7)
- `docs/03-requirements.md` (FTK-REQ-001 v0.7)
- `docs/04-calcs/01-sizing.md` (FTK-CAL-001 v0.5)
- `docs/05-build-plan.md` (FTK-BLD-001 v0.3)
- `README.md` (not a controlled document)

### Follow-up actions to carry approved decisions into the design

1. Decision 2: Calculations: change the rated cargo in `docs/04-calcs/sizing.py` to 148 kg (80 kg rider) and 138 kg (90 kg rider) and R8 to 72 kg, and rerun so the mass, tipping and braking figures and `results.csv` use the restated rating and statuses.
2. Decision 2: Model and calculations: try lightening windows in the knuckle post arms and yokes (about 0.5 kg) and a lighter box in the FEA session; set the final load label from the weighed trike.
3. Decision 3: Calculations: change R14's target in `sizing.py` to 60 min for a knuckle post plate.
4. Decision 5: Model: add a steering lock stop at each knuckle post that its steering arm clamp plate meets at 40 degrees, with a constructability check that the stop is met at 40 degrees on both sides.
5. Decision 5: Drawings: add a making sketch for the lock stop and show it on FTK-DWG-001.
6. Decision 5: Build plan pictures: show the lock stops in the knuckle post making sketch and in steps 14 and 17, and list the stop in the build plan's parts (review flag 2).
7. Decision 5: BOM: add the two lock stops (and their bolts) to the knuckle post line.
8. Decision 7: Calculations: add a steering geometry study (caster, trail, kingpin inclination, scrub radius, self-centring) to FTK-CAL-001 in the FEA session, with the bought fork's rake as input, before the first ride.
9. Decision 1: Calculations: compute the turning circle from the built linkage (31.3 degrees at the outer wheel) instead of ideal Ackermann (review flag 1).
10. Decision 1: Renders: regenerate the photoreal renders, `media/card.png` and `media/social-preview.png` on Amish's Mac to show the accepted design for construction (items 9 and 10 follow with them).

### Points found in the review

1. The turning circle calculation still uses ideal Ackermann, while the built linkage gives 31.3 degrees at the outer wheel against 29.5 degrees ideal.
2. Item 5 says the stop is 'a part to add before the first ride, not before the build'; since it is safety-critical, it should be in the build plan's parts list.

No CAD model, BOM quantity or price, calculation result or picture was changed. TRL stays at 3; TRL 4 remains on hold.

## Session 2026-10-02: approved follow-ups carried out

Amish approved carrying out every follow-up action from the open-decision sign-off ("APPROVED CHANGES, COMPLETE THESE") and preparing the render scenes. This session carried the decisions of 2026-10-02 into the model, BOM, calculations, drawings, pictures and appearance model. TRL stays at 3; TRL 4 remains on hold.

### Follow-ups

1. Rated cargo 148 and 138 kg and R8 72 kg in `sizing.py`: **done.** Re-run on the model with the lock stops: empty 71.7 kg (0.3 kg under R8), gross 299.7 kg in both cases; tipping, braking and `results.csv` at the restated rating.
2. Lightening windows and a lighter box; final load label: **not done:** the decision places the trial in the FEA session and the label on the weighed trike (TRL 4). The R8 margin is now only 0.3 kg, so the trial matters.
3. R14 60 min for a knuckle post plate in `sizing.py`: **done** (53 min, 7 min margin).
4. Steering lock stop at each knuckle post with a constructability check: **done.** A 77 x 130 mm fin tabbed and bolted to each front knuckle post plate; the steering arm clamp plates lengthened to 93 mm so their front inboard corner meets it. `python cad/src/model.py --check` passes: 167 components, 37 plates, 97 bolt sets, no overlaps, no sweep issues, each clamp plate meets its stop at 40° and not 1° before. STEP and STL regenerated.
5. Making sketch for the lock stop and the stop on FTK-DWG-001: **done** (FTK-DWG-124 P1; FTK-DWG-001 Rev P4 with a lock stop note and the new figures).
6. Lock stops in the knuckle post making sketch, steps 14 and 17 and the build plan parts: **done** (FTK-DWG-114 P2, FTK-DWG-119 P2, new section 3.24, steps 13 to 21 and joints 9 and 11 redrawn).
7. Two lock stops and bolts in BOM line 3: **done** ($89, was $85; basis in `bom/bom-notes.md`). Base prototype $728.
8. Steering geometry study: **done as a first pass** (FTK-CAL-001 section 5a): head tubes vertical, so no caster, kingpin inclination or scrub; a fork fitted with its offset forward gives negative trail (about 6.6 N·m per wheel pulling into the turn at 0.2 g with a 30 mm offset). The repeat with the chosen fork's measured rake stays in the FEA session, as decided.
9. Turning circle from the built linkage: **done.** 31.3° at the outer wheel; 5.64 m outer tyre circle (5.95 m upper bound).
10. Photoreal renders, `media/card.png` and `media/social-preview.png`: **not done:** made on Amish's Mac. The appearance model and render scenes are prepared (below).

### Requirement status changes

None. R1, R8 and R14 stay met on paper (now computed rather than restated); R8's margin fell from 0.8 kg to 0.3 kg. R7 is about 4.07 h (97 bolt sets), still at risk as accepted. R9 improves to 5.64 m. R15: Value-engineering target: USD 800. Estimated cost of the constructable design: USD 728 (USD 72 under the target). R18 about $466, USD 166 over its target.

### Documents changed

- `cad/src/model.py`, `cad/step/*`, `cad/stl/*` (lock stops, longer clamp plates, lock stop check)
- `bom/bom.csv`, `bom/bom-notes.md`
- `docs/04-calcs/sizing.py`, `docs/04-calcs/results.csv`, `docs/04-calcs/01-sizing.md` (FTK-CAL-001 v0.6)
- `docs/03-requirements.md` (FTK-REQ-001 v0.8)
- `docs/02-concept.md` (FTK-PRC-001 v0.8)
- `docs/05-build-plan.md` (FTK-BLD-001 v0.4): new section 3.24 and Figure 37 (later figures renumbered); "Pictures unchanged" no longer applies
- `docs/06-design-decisions.md` (FTK-DEC-001 v0.4): value engineering restated
- `cad/drawings/FTK-DWG-001` Rev P4; `FTK-DWG-114` P2, `FTK-DWG-119` P2, `FTK-DWG-124` P1 (new)
- `docs/05-build-plan/overview.png`, `joint-09.png`, `joint-11.png`, `step-13.png` to `step-21.png`
- `media/` concept media (blueprint FTK-DWG-010 P3, hero, exploded, flow, model.glb)
- `cad/src/product_model.py`: the frame, bed, knuckle posts, lock stops, steering and every bolt set now come from `model.build_components()`; chain guard and crank spider moved outboard of the right-hand chain line. Render scenes exported to `/home/claude/renders/flattrike` (hero, exploded, detail)
- `README.md` (not a controlled document)

### Appearance model deviations (each Proposed, awaiting Amish)

- The plates are drawn as cut (no extra corner radii), and the wheels, drivetrain, seat, bars, box hardware and cable runs keep their 2026-09-26 appearance detail. Recommendation: accept as appearance only.

### Cross-repo actions

None.

### Safety concerns

- A knuckle fork fitted as sold, offset forward, gives negative trail on the vertical knuckle head tubes; the steering would pull into turns. Settle fork orientation or caster in the FEA-session study before the first ride (S6).
- The lock stop takes the whole bar torque on one side (about 0.84 kN); its fin and bolt are within limits on paper.

### Recommended next step

Renders on Amish's Mac from the exported scenes; then the FEA session (plate-and-joint FEA, lightening windows for the 0.3 kg R8 margin, and the steering geometry study with the chosen fork). **TRL 4 remains on hold by Amish's instruction.**

## 2026-10-02: photoreal renders redone on the constructable design

Rendered with Blender Cycles on Amish's Mac from the updated appearance model; captioned with `.kit/photo_caption.py`; `media/card.png` and `media/social-preview.png` regenerated with `.kit/cards.py`. Views: hero, exploded, detail. image_qc passes. Appearance deviations are those logged above as proposed, awaiting Amish.

## Session 2026-10-03: fork direction settled (forks turned to trail)

On 2026-10-03 Amish wrote: "FlatTrike - i accept your design recommendation, proceed and execute the solution for fork direction or caster". The first-pass study (FTK-CAL-001 v0.6, section 5a) had named turning each knuckle fork round so its offset trails as the first option; this session carried it out. TRL stays at 3; TRL 4 remains on hold.

### Solution and why

- Each knuckle fork is a 20 in steel fork with a threaded 1 1/8 in steerer and straight BMX-type legs parallel to the steerer, 30 to 40 mm offset, fitted turned round so the axle trails the vertical knuckle head tube. Mechanical trail 35 mm in the model (30 to 40 mm over the fork range); caster 0°, kingpin inclination 0°, scrub 0 mm, all measured on the model by `model.py --check`.
- Why this and not head tube caster: it needs no new or angled plates, keeps the knuckle posts, collar plates, headsets, ride height and linkage as they are, and gives no wheel flop. Caster would have meant redrawing the knuckle posts round a tilted head tube. Straight legs are needed because the steering arm clamps to the leg; a bent-leg fork turned round would put the clamp on the bend.
- Why 35 mm: 30 to 70 mm is the target band (below about 30 mm the centring torque is small against the friction of three headsets and two rod-end links; above about 70 mm the 2.25 kN front load makes the bar heavy and kicks back). The lower part of the band suits a slow, tightly steered front loader, and 35 mm comes from stock forks. Centring torque at the column 15.7 N·m at 0.2 g loaded (26 N per grip).

### Knock-on changes and effects

- Wheelbase 1.45 to 1.415 m (kingpins unchanged at 1.45 m). Turning circle 5.64 to **5.52 m** (R9 met; 5.86 m upper bound). Tipping thresholds rise slightly (0.42 g loaded, 0.24 g rider only; R10 met). Lock 40°, Ackermann arms, tie rod, toe (zero) and 1:1 bar ratio unchanged; tyre scrub at full lock 0.20 m (was 0.18 m).
- Bed rails: a tyre notch 55 mm up into the lower edge, 1,200 to 1,305 mm from the rear axle, because the trailing inner tyre swings 22.5 mm further across at full lock and otherwise struck the rail. 39 MPa in the 55 mm of plate left. Two rail windows shortened.
- Knuckle post plates: lower lip 8 mm past the outer cheek (was 10 mm) for the fork crown's larger swing.
- Steering arm clamp plates 67 x 40 mm (inboard end 104 mm from the kingpin, was 130 mm), steering arms shorter, lock stop fins 34 x 130 mm (were 77 x 130 mm). Stop force 0.82 kN at 109 mm.
- Least running clearances over the sweep (new check, 5 mm minimum): inner tyre to the box side **7.7 mm** at full lock (about 33 mm before); fork crown to knuckle post plate 5.9 mm.
- Mass 71.6 kg empty (0.4 kg under R8). Rear axle load falls (0.69 kN loaded); rear tyre grip needed on 5 % rises from 0.26 to 0.28.
- Cost: BOM line 5 $92 to $100 (straight-leg forks about $4 more each). Base prototype **$736** (USD 64 under the $800 target); production about $471 (R18 USD 171 over).

### Files changed

- `cad/src/model.py` (FORK_OFFSET, axle_x(), TRAIL_RANGE, RAIL_NOTCH, POST_LIP, CLAMP_IN; new trail, scrub and running-clearance checks), `cad/step/*`, `cad/stl/*`. `python cad/src/model.py --check`: PASS (167 components, 0 overlaps, 0 floating, 0 joint, sweep, lock stop, clearance or geometry issues).
- `docs/04-calcs/sizing.py`, `results.csv`, `01-sizing.md` (FTK-CAL-001 v0.7; section 5a rewritten)
- `docs/03-requirements.md` (FTK-REQ-001 v0.9), `docs/02-concept.md` (FTK-PRC-001 v0.9), `docs/05-build-plan.md` (FTK-BLD-001 v0.5), `docs/06-design-decisions.md` (FTK-DEC-001 v0.5), `bom/bom.csv`, `bom/bom-notes.md`, `README.md`
- Drawings: FTK-DWG-001 Rev P5; FTK-DWG-112 P2, 114 P3, 116 P2, 118 P2, 119 P3, 124 P2
- Build plan pictures: `overview.png`, `joint-08.png`, `joint-09.png`, `joint-11.png`, `step-11.png` to `step-21.png`
- Concept media (blueprint FTK-DWG-010 P4, hero, exploded, flow, model.glb)
- `cad/src/product_model.py`: front wheels and mudguards at the trailing axle; forks come from the model (straight legs). Render scenes exported to `/home/claude/renders/flattrike` (hero, exploded, detail). Photoreal renders, `media/card.png` and `media/social-preview.png` not redone (Amish's Mac).

### Proposed, awaiting Amish

1. Front mudguards: with 7.7 mm from tyre to box side at full lock, a full-length front mudguard would rub the box. Options: (a) short front mudguards that stop above the axle at the rear; (b) reduce the inner lock to about 37° (turning circle about 5.8 m, R9 still met); (c) no front mudguards. Recommendation: (a).
2. The 2026-10-02 appearance decision accepted "bent fork legs" as appearance only; the forks are now straight-leg by design and the appearance model already shows them straight. Recommendation: note that item as superseded.

### Safety concerns

- A fork fitted as sold (legs forward) gives 35 mm of negative trail and pulls the steering into turns. Step 16 now has a hold point and S6 requires both forks checked turned round before the first ride.
- Pneumatic trail, shimmy and kickback with 35 mm trail are not quantified; the FEA session repeats the geometry with the chosen fork's measured offset.

### Recommended next step

Photoreal renders and cards on Amish's Mac from the exported scenes; then the FEA session (plate-and-joint FEA, lightening windows for the 0.4 kg R8 margin, steering geometry with the measured fork). **TRL 4 remains on hold by Amish's instruction.**

## 2026-10-02: photoreal renders redone on the constructable design

Rendered with Blender Cycles on Amish's Mac from the updated appearance model; captioned with `.kit/photo_caption.py`; `media/card.png` and `media/social-preview.png` regenerated with `.kit/cards.py`. Views: hero, exploded, detail. image_qc passes. Appearance deviations are those logged above as proposed, awaiting Amish.

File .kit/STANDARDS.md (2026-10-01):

---
doc_id: OHP-STD-001
title: Documentation and drawing standard
project: Open Hardware Portfolio
doc_type: Standard
version: "1.7"
status: Released
date: 2026-09-30
author: Amish Chadha
license: CC-BY-SA-4.0
revisions:
  - version: "1.0"
    date: 2026-09-24
    author: Amish Chadha
    change: First release of the standard
  - version: "1.1"
    date: 2026-09-24
    author: Amish Chadha
    change: Adopt Technology Readiness Levels (section 9) for project maturity
  - version: "1.2"
    date: 2026-09-24
    author: Amish Chadha
    change: Portfolio phase cap (section 10), concept media standard (section 11), CLAUDE.md guardrails
  - version: "1.3"
    date: 2026-09-24
    author: Amish Chadha
    change: Scale figure, interactive 3D viewer and flow diagrams added to concept media; session slash commands
  - version: "1.4"
    date: 2026-09-26
    author: Amish Chadha
    change: Every sheet and render names the project and its GitHub repository; overall dimensions, ISO centre lines and 300 dpi PNG on sheets; titles name the device and view labels state the viewing direction; optional photoreal renders with Blender
  - version: "1.5"
    date: 2026-09-27
    author: Amish Chadha
    change: Product renders (section 12), storefront images and image quality check (section 13), public release and release gate (section 14), authorship, citation and commit signing (section 15)
  - version: "1.6"
    date: 2026-09-29
    author: Amish Chadha
    change: Licensing metadata with REUSE (section 16), Zenodo DOI and Software Heritage archiving (section 17), release gate checks REUSE and a single CITATION.cff license, archive.py
  - version: "1.7"
    date: 2026-09-30
    author: Amish Chadha
    change: Concept and constructable design states; design decisions register (DEC) kept apart from the build plan; prototype build plan (BLD, section 18) with pictures by component is required TRL 3 evidence; every repo targets TRL 3 during the populate phase; build_views.py; /to-trl3 and /build-plan commands
---

# Documentation and drawing standard

Every project in the portfolio uses this standard, so that each precis, write-up and sketch looks the same and carries its own version history. The standard ships as a kit in each repo's `.kit/` folder. The kit version is in `.kit/KIT_VERSION`.

## 1. Document types and IDs

Every controlled document has a unique ID in the form `PRJ-TYP-NNN`.

- `PRJ` is the three-letter project code listed in section 7.
- `TYP` is the document type code from the table below.
- `NNN` is a sequence number within that project and type, starting at 001.

| Code | Type | Typical file |
| --- | --- | --- |
| PRC | Design precis | `docs/02-concept.md` |
| PRB | Problem statement | `docs/01-problem.md` |
| REQ | Requirements | `docs/03-requirements.md` |
| CAL | Calculation or sizing note | `docs/04-calcs/*.md` |
| DDR | Design decision record | `docs/decisions/*.md` |
| BOM | Bill of materials | `bom/bom.csv` |
| DWG | Drawing or sketch sheet | `cad/drawings/*.svg` |
| BLD | Prototype build plan (section 18) | `docs/05-build-plan.md` |
| DEC | Design decisions register (section 18) | `docs/06-design-decisions.md` |
| TST | Test plan or test report (front matter adds `environment: lab` or `relevant`) | `docs/05-tests/*.md` |

Example: `TBK-PRC-001` is the ThermaBrick design precis.

## 2. Revision scheme

| Artifact | While in draft | When released | Change after release |
| --- | --- | --- | --- |
| Documents | 0.1, 0.2, 0.3 ... | 1.0 | 1.1 for minor edits, 2.0 for a design change |
| Drawings | Rev P1, P2 ... (preliminary) | Rev A | Rev B, C ... |

- Every change to a controlled document adds a row to its revision history before the commit.
- The `version` field in front matter always equals the newest row in `revisions`. The renderer rejects a document where they differ.
- Status is one of `Draft`, `In review`, `Released` or `Superseded`. Draft and In review documents print with a status band on every page.
- Every release is tagged in Git as `<doc_id>/v<version>`, for example `TBK-PRC-001/v1.0`. Drawings are tagged `TBK-DWG-001/revA`.
- Git history is the full audit trail. The in-document revision table is the human-readable summary.

## 3. Document front matter

Every Markdown document under version control starts with this block:

```yaml
---
doc_id: TBK-PRC-001
title: ThermaBrick design precis
project: ThermaBrick
doc_type: Precis
version: "0.1"
status: Draft
date: 2026-09-24
author: Amish Chadha
license: CERN-OHL-S-2.0
revisions:
  - version: "0.1"
    date: 2026-09-24
    author: Amish Chadha
    change: Initial draft
---
```

Quote version numbers so YAML keeps `1.0` as text instead of turning it into a number. List revisions newest last.

## 4. Writing style

- Chicago Manual of Style.
- No em dashes. Restructure the sentence instead.
- Lead each section with its conclusion, then support it.
- SI units throughout, in the form `12 kW`, `450 °C`, `3.2 m`. Imperial values may follow in parentheses.
- Number every figure and table ("Figure 2", "Table 1") and give each a caption.
- State every assumption in the calculation that depends on it.
- Put safety notes in a blockquote starting with **Safety:**.

## 5. Visual identity

| Element | Specification |
| --- | --- |
| Typeface | IBM Plex Sans for text, IBM Plex Mono for code and values (SIL Open Font License, bundled in `.kit/fonts`) |
| Ink | `#111827` |
| Secondary text | `#4B5563` |
| Rules and grid | `#D1D5DB` |
| Accent (one only) | `#0F766E` teal |
| Document page | US Letter, 20 mm margins |
| Drawing sheet | ANSI B landscape (431.8 x 279.4 mm) |
| Footer | Document ID, version, status, license and designmolecule.com on every page |

## 6. Drawing and sketch conventions

- Units are millimeters unless the title block says otherwise.
- Third-angle projection, marked with the symbol in the title block.
- Line weights: visible outlines 0.5 mm, hidden lines 0.25 mm dashed, center lines 0.18 mm chain.
- The title block contains the project, title, drawing number, revision, scale, units, projection, sheet, author, date, material or notes, and license.
- Every sheet and every render names the project and its GitHub repository (from `repo:` in `project.yaml`), at the top of the sheet and in the title block, so a printed or forwarded sheet is never anonymous.
- The drawing title names the device, not only the drawing type (for example "Handheld near-infrared resin scanner: general arrangement").
- Every view label states its scale and viewing direction (for example "Scale 1:1; side elevation looking along +Y"), and every isometric or render states where it is seen from.
- Orthographic views generated with `add_ortho` carry overall dimensions (length and depth on the top view, height on the front view) and ISO 128 centre lines on cylinders; hidden lines are dashed. Tolerances are not shown before TRL 4.
- Sheets are exported as SVG, PDF and a 300 dpi PNG.
- The revision table in the top right of the sheet lists every revision.
- Concept sketches use the same sheet and title block and carry the label "CONCEPT, NOT FOR FABRICATION".
- Geometry comes from `cad/src/*.py` (build123d). Sheets are generated by `.kit/drawing.py` and never edited by hand.

## 7. Project codes

| Code | Project | Code | Project | Code | Project |
| --- | --- | --- | --- | --- | --- |
| TBK | ThermaBrick | PCF | PicoFlow | HLT | HelioLite |
| CCB | CharCube | DRN | DustRunner | TRT | TremorTrace |
| STC | StepCue | FXH | FlexHand | CPD | ColdPod |
| SCL | SunClave | STR | SteamRoot | GGD | GrainGuard |
| SDL | SeedLine | ZBX | ZeerBox | RMS | RootMesh |
| DWD | DewDrive | SSK | StillStack | PPR | PotPress |
| WWT | WaterWatch | LMF | LumaFlow | FCL | FieldCell |
| CNP | ConePro | CVC | CulvertCrawl | EGD | EmberGuard |
| SNF | SnapFrame | CGM | CargoMule | SCM | StepClimber |
| SWC | SwapCell | PLP | PalletPilot | FTK | FlatTrike |
| WWK | WaterWalker | GRR | GrowRider | SSP | SunSpoke |
| SGN | StepGen | PBX | PowerBox | WML | WasteWise-ml |
| WSC | WasteWise Scan | RFE | ReflowEconomy | | |
| OHP | Portfolio-wide | | | | |

## 8. Build and publish

- `python .kit/render.py` checks every controlled document and renders it to `docs/pdf/<doc_id>_v<version>.pdf`.
- `python .kit/drawing.py` (called from each project's `cad/src/sheets.py`) builds drawing sheets as SVG and PDF in `cad/drawings/`.
- The GitHub Action in `.github/workflows/docs.yml` runs the checks on every push and attaches PDFs to a GitHub Release whenever a release tag is pushed.
- Public releases follow section 14: `python .kit/release_gate.py` must pass, and the release tag is `v0.<TRL>.0` (for example `v0.3.0` at TRL 3).
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

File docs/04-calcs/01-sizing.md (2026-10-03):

---
doc_id: FTK-CAL-001
title: FlatTrike sizing and first-principles checks
project: FlatTrike
doc_type: Calculation note
version: "0.7"
status: Draft
date: '2026-10-03'
author: Amish Chadha
license: CERN-OHL-S-2.0
revisions:
- version: "0.1"
  date: '2026-09-25'
  author: Amish Chadha
  change: First TRL 3 sizing note (geometry, nesting, mass, power, stability, structure, braking, assembly, cost) against every requirement
- version: "0.2"
  date: '2026-09-25'
  author: Amish Chadha
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

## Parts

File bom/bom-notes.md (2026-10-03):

# BOM notes

- All costs are indicative USD prices for a single prototype, updated at TRL 3 (2026-09-25). No supplier quotes have been obtained; they are needed from the target city once a partner is chosen.
- Item numbers 1 to 12 match the callouts in `media/exploded.png` and the parts in `cad/src/model.py`. Items 13 to 15 are not modelled.
- Plate costs assume 3 mm S235JR or A36 class steel at about $1.2 per kg and small-batch laser cutting. Net plate areas come from the model: spine 0.34 m², stays 0.30 m², front bed and knuckle posts 0.54 m² (FTK-CAL-001 v0.2).
- Base prototype, pedal only (items 1 to 14): **$736**, within the $800 `budget_usd` in `project.yaml` (FTK-REQ-001 R15). `docs/04-calcs/sizing.py` checks this total from this file.
- Item 15, the route C assist kit (48 V mid-drive and a SwapCell vehicle receiver to latch class V1), is optional and **not** in the base cost. The SwapCell pack is priced once in the SwapCell repo and excluded here (decided by Amish, 2026-09-25, FTK-DDR-001).
- Item 5 rose from $25 to $85 when Ackermann steering with a fixed box was decided (FTK-DDR-002 item 13): central steering column, two knuckle headsets and head tubes, two 20 in forks, drag link and tie rod. Item 14 now includes the cornering-speed label (FTK-DDR-002 item 15, R10).
- Production estimate at 100 units: about $466 per trike against the $300 value-engineering target, USD 166 over (R18). The target stays until the first partner supplies wholesale prices (FTK-DDR-002). See FTK-CAL-001 section 9.
- Design for construction (FTK-DDR-003, 2026-10-01): line 4 now counts 95 bolt sets (was 116), two seat tube saddles, 78 washers and four spacer tubes ($35, was $38); line 5 adds a third fork cut down as the steering column and four U-bolts ($92, was $85); line 10 adds a bought seat tube and two shaft collars ($24, was $18); line 11 a tall quill stem ($20, was $15). Base prototype $724 (was $709).
- Steering lock stops (decided by Amish 2026-10-02, FTK-DEC-001): line 3 adds two lock stop fins (77 x 130 mm, cut in the same pass as the other plates, about $1.75 each with cutting at the small-batch rate used for the other plates) and two M8 bolt sets for them (about $0.26 each, the stockist price used for line 4): $89, was $85. The two steering arm clamp plates in line 5 are 45 mm longer so their inboard corners reach the stops; cut in the same pass, no price change. Base prototype $728 (was $724). The stops, their bolts and the longer clamp plates add about 0.5 kg: empty mass 71.7 kg against the 72 kg limit of R8 (FTK-CAL-001 v0.6).
- Fork direction (decided by Amish 2026-10-03, FTK-DEC-001): the two knuckle forks are now specified as 20 in steel forks with a threaded 1 1/8 in steerer and BMX-type legs parallel to the steerer at 30 to 40 mm offset, fitted turned round so the offset trails (35 mm of mechanical trail in the model). A plain bent-leg 20 in fork is about $12 in the spares market; a straight-leg BMX-type steel fork about $16, so line 5 rises by about $8 to $100 (was $92). The two bed rails gain a tyre notch, the lock stop fins shrink to 34 x 130 mm and the clamp plates and steering arms shorten; all are cut in the same pass, so line 3 stays $89. Base prototype $736 (was $728). The plate changes save about 0.2 kg: empty mass 71.6 kg (FTK-CAL-001 v0.7).

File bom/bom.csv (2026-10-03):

item | qty | spec | supplier | unit_cost_usd | make_buy | notes
1 Spine plates and covers | 1 | 3 mm S235JR or A36 steel: two side plates about 681 x 585 mm with 35.5 mm bottom bracket holes, two lightening windows and a 75 mm level edge under the head tube; top cover 676 x 90 mm with an oval seat tube hole; bottom cover 220 x 90 mm; tabs, slots and T-slots cut in the same pass (FTK-DDR-003) | Local laser or waterjet job shop | 45.00 | make | Indicative TRL 3 price (steel about $12 plus cutting); 0.34 m2 net; closed box for torsion (FTK-CAL-001)
2 Rear stay plates (pair) | 1 | Two 3 mm steel plates about 745 x 555 mm with dropout slots for a 120 mm hub and a reduced window (upper strip 100 mm or wider) | Local laser or waterjet job shop | 36.00 | make | Indicative TRL 3 price; 0.30 m2 net
3 Front bed and knuckle post plates | 1 | 3 mm steel: lower and upper yoke (they clamp the head tube), bulkhead with two windows, two bed rails (each with a tyre notch in its lower edge behind the axle beams), two axle beam plates with halving slots, and per side a knuckle post (two post plates, an inner and an outer cheek) with two knuckle collar plates and a steering lock stop (a 34 x 130 mm fin tabbed and bolted to the front post plate's front face; the steering arm clamp plate meets it at full lock); tabs, slots and T-slots cut in the same pass; two M8 bolt sets for the two stops | Local laser or waterjet job shop | 89.00 | make | Indicative TRL 3 price; about 0.55 m2 net; fixed bed with knuckle posts for Ackermann steering (FTK-DDR-002 item 13); yokes and knuckle posts redesigned for construction (FTK-DDR-003); lock stops added 2026-10-02 (FTK-DEC-001): two fins cut in the same pass about $3.50, two bolt sets about $0.50; rail tyre notches and smaller fins with the forks turned to trail (2026-10-03): same cutting pass, no price change
4 Ribs saddles spacers and M8 bolts | 1 | Two spine ribs, stay bridge, two seat tube saddles, 78 cut spacer washers (stacks of 9 at the stay bolts, of 3 behind the box), four 60 mm spacer tubes cut from 16 x 2 mm steel tube; 95 sets of M8 class 8.8 zinc-plated bolts (25 mm for the tab joints, 140 mm for the stay bolts), washers and all-metal prevailing-torque locknuts | Laser shop plus industrial fastener stockist | 35.00 | buy | Indicative; plates, washers and tubes about $10; bolt sets about $0.26 each; all-metal locknuts decided (FTK-DDR-001); each tab joint's locknut sits in a window in the plate (FTK-DDR-003)
5 Steering column knuckles and linkage | 1 | Central 1 1/8 in threaded headset in a 200 mm steel head tube section (40 mm OD) clamped between the yokes by its cups; steering column from a bought threaded fork with a forged crown, legs cut off, drilled for the drop arm; two 1 1/8 in threaded headsets in 120 mm head tube sections; two 20 in steel forks (100 mm dropouts) with a threaded 1 1/8 in steerer and BMX-type legs parallel to the steerer, 30 to 40 mm offset, each fitted turned round so its offset trails (35 mm mechanical trail); drop arm, two Ackermann steering arms and two arm clamp plates cut from plate; four M6 U-bolts; drag link and tie rod with three M8 rod ends (10 deg or more misalignment) | Bicycle spares market | 100.00 | buy | Indicative; Ackermann steering with a fixed box decided (FTK-DDR-002 item 13); 200 mm head tube decided (item 19); third fork for the column and U-bolts added (FTK-DDR-003); knuckle forks specified as straight-leg 30 to 40 mm offset forks turned to trail (decided 2026-10-03; about $4 more each)
6 Front wheels with drum brakes | 2 | 20 x 2.125 in (ISO 406) 36H rim, 90 mm class front drum brake hub for 100 mm fork dropouts (about 37 N m braking torque needed), tyre and tube | Bicycle spares market | 55.00 | buy | Indicative; drum torque rating to confirm with the hub maker
7 Rear wheel with 3-speed drum hub | 1 | 20 x 2.125 in (ISO 406) 36H rim, 3-speed hub gear with built-in drum brake, 120 mm OLD, 24T sprocket, shifter, tyre and tube | Bicycle spares market | 95.00 | buy | Indicative; hub input torque limit to confirm for the 32/24 gearing
8 Drivetrain | 1 | 68 mm steel bottom bracket shell section cut to 60 mm (its cups clamp the spine plates), square-taper cartridge bottom bracket, 170 mm cranks, 32T chainring, 1/8 in chain, pedals, chain guard; right-hand drive | Bicycle spares market | 38.00 | buy | Indicative; 44 mm chain line on the right, between spine and stay (FTK-DDR-003)
9 Cargo box and lid | 1 | Exterior plywood box 820 x 560 x 360 mm: 12 mm floor, 9 mm walls and lid, hinges, hasp and padlock, sealant and paint; eight M8 bolts with penny washers to the bed; four counterbores in the sides | Local carpenter | 60.00 | make | Indicative; about 151 L inside; floor at 0.47 m clears the steered wheels; lid at 0.84 m doubles as a counter
10 Seat tube seatpost and saddle | 1 | Bought 31.8 x 2.3 mm steel seat tube 225 mm long, two 32 mm shaft collars, seat clamp, 27.2 mm steel seatpost, sprung saddle | Bicycle spares market | 24.00 | buy | Indicative; seat tube held in two cut saddles across the spine (FTK-DDR-003)
11 Handlebar and stem | 1 | Steel riser bar, tall quill stem (about 350 mm quill) in the steering column, grips | Bicycle spares market | 20.00 | buy | Indicative; tall quill stem sets the bar at 850 mm (FTK-DDR-003)
12 Brake levers cables and parking latch | 1 | Two brake levers (front-pair lever with parking lock), cable splitter for the two front drums, cables and housing | Bicycle spares market | 22.00 | buy | Indicative; latch holds the front pair (about 37 N m per drum on a 10 % grade)
13 Primer and paint or powder coat | 1 | Deburr all plates, zinc-rich primer and enamel, or powder coat; seal plate edges and joint faces | Local paint or powder-coat shop | 35.00 | buy | Indicative; no exploded-view callout
14 Accessories | 1 | Mudguards, reflectors, bell, rubber bumpers for the box, cornering-speed label on the bar (empty: 6 km/h in full-lock turns) | Bicycle spares market | 27.00 | buy | Indicative; no exploded-view callout; label decided with the R10 change (FTK-DDR-002 item 15)
15 Optional electric assist kit (route C) | 1 | 48 V 250 W mid-drive kit with controller and display, plus a SwapCell vehicle receiver to latch class V1; SwapCell pack not included | E-bike parts supplier plus laser shop | 300.00 | buy | Optional; not in the base prototype (assist option A decided for the prototype); SwapCell pack priced once in the swapcell repo and excluded from this budget

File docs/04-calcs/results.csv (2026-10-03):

quantity | value | unit | note
Overall length | 2.146 | m
Overall width | 0.986 | m
Overall height (saddle top) | 0.93 | m
Wheelbase | 1.415 | m | front axles trail the knuckle steering axes (1.45 m) by the fork offset
Front track | 0.84 | m
Cut plates (count) | 37
Plate area, net of windows | 1.308 | m2
Plate mass (3 mm, 23.6 kg/m2) | 30.8 | kg
Spacer washers cut from offcuts (8 stacks of 9 at the stay nodes, 2 of 3 behind the box) | 78
Shelf-nest of bounding rectangles: sheet length used (of 2500 mm) | 2669 | mm | 9 shelves; conservative, ignores the plates' shapes and windows
Sheet utilisation by net area | 41.85 | %
True-shape raster nest: sheet length used (of 2500 mm) | 1985 | mm | 37 of 37 plates placed; 5 mm raster, 10 mm or more between parts, small parts in windows
Box inside volume | 151.3 | L
Lid (counter) height | 0.839 | m
Box mass (12 mm floor, 9 mm walls and lid, 700 kg/m3) | 12.73 | kg
Flat stack of plates and box panels | 204.6 | mm
Crate: plates and panels 0.86 x 0.62, three wheels and forks stacked beside | 0.308 | m3 | 1.38 x 0.62 x 0.36 m
Longest cut plate | 852 | mm
Longest single piece (box floor panel) | 820 | mm
Bolt sets (count) | 97
Bolts and spacer washers | 3.587 | kg
Empty mass | 71.57 | kg | R8 target 72 kg (relaxed 2026-10-02; 70 kg before)
Margin under R8 | 0.4319 | kg
Plate share of empty mass | 43.03 | %
Box share of empty mass | 17.79 | %
Gross mass, 80 kg rider and 148 kg cargo | 299.6 | kg | R1 limit 300 kg
Gross mass, 90 kg rider and 138 kg cargo | 299.6 | kg | R1 limit 300 kg
Cargo allowed with an 80 kg rider inside 300 kg | 148.4 | kg | R1 rated cargo 148 kg
Cargo allowed with a 90 kg rider inside 300 kg | 138.4 | kg | R1 rated cargo 138 kg
Rider centre of mass ahead of rear axle | 0.4243 | m
Rider centre of mass height | 1.09 | m
Empty trike CoM ahead of rear axle | 0.9848 | m
Empty trike CoM height | 0.4989 | m
Front axle load, loaded (static) | 2.245 | kN
Rear axle load, loaded (static) | 0.6941 | kN
Rear axle load, rider only (static) | 0.7629 | kN
Rolling resistance at gross mass | 44.08 | N
Power at the rear wheel from 110 W | 97.9 | W
Cruise speed, flat | 7.583 | km/h | R12 target 7 km/h
of which rolling | 92.85 | W
of which drag | 5.047 | W
Force on a 5 % grade | 191 | N
Wheel power at 4 km/h on 5 % | 213 | W
Pedal power at 4 km/h on 5 % | 239.3 | W | R13; rider sustains 110 W
Unassisted speed on 5 % at 110 W | 1.844 | km/h
Rear tyre grip needed on 5 %, loaded (rear-wheel drive) | 0.2752 |  | friction coefficient
Wheel torque on 5 % | 48.52 | N m
Development, low gear | 1.596 | m per crank rev
Development, middle gear | 2.128 | m per crank rev
Development, high gear | 2.836 | m per crank rev
Cadence at 4 km/h in low gear | 41.77 | rpm
Speed at 70 rpm in high gear | 11.91 | km/h
Mean crank torque on 5 % in low gear | 54.52 | N m
Mean pedal force at 170 mm | 320.7 | N
Speed on 5 % with 250 W mid-drive plus rider | 5.991 | km/h | assist route C
Assist battery use, flat at 12 km/h | 8.08 | Wh/km
SwapCell range, flat at 12 km/h | 56.56 | km
Assist battery use, 5 % climb | 52.16 | Wh/km
Inner wheel lock (box clearance limit) | 40 | deg
Outer wheel lock (ideal Ackermann, for comparison) | 29.29 | deg
Outer wheel lock through the built linkage at 40 deg inner lock | 31.29 | deg | the trapezoid only approximates Ackermann; the turning circle below uses the built linkage
Column (handlebar) turn at full inner lock, left wheel through the drag link | 40 | deg | drop arm parallel to the left steering arm (FTK-DDR-003); was about 1.7 times the wheel angle
Turn centre from the centre line, outer wheel's axle line (built linkage) | 1.898 | m
Turn centre from the centre line, inner wheel's axle line | 2.094 | m
Turn centre mismatch between the front wheels (tyre scrub at full lock) | 195.4 | mm
Turning circle, outer tyre, built linkage | 5.522 | m | R9 target 6 m
Turning circle, outer tyre, if the turn centre stayed on the inner wheel's axle line (upper bound) | 5.86 | m | the inner wheel's turn centre
Swept circle, box front corner (inner wheel's turn centre, upper bound) | 6.071 | m
Steering lock stop: met by each clamp plate at (inner wheel) | 40 | deg | constructability check in model.py --check
Steering lock stop: lever of the contact force about the kingpin axis | 109.2 | mm
Stop force, rider forcing the bar into the lock (300 N at one grip, 300 mm) | 823.9 | N | one stop takes the whole bar torque; the force lies in the fin's plane
Stop fin lower leg, in-plane bending stress | 45.77 | MPa | 30 mm wide leg; yield 235 MPa
Stop fin lower leg, out-of-plane stress from contact friction (mu 0.2) | 91.54 | MPa
Stop fin T-slot bolt tension (fin pivots on its top corner) | 1336 | N | M8 8.8 preload 15.6 kN
Caster angle, measured on the model (knuckle head tubes vertical) | 0 | deg
Kingpin inclination, measured on the model | 0 | deg
Scrub radius, measured on the model | 0 | mm | steering axis in the wheel's centre plane
Fork offset, fitted turned round (model) | 35 | mm | buy 30 to 40 mm, legs parallel to the steerer
Mechanical trail, measured on the model | 35 | mm | target 30 to 70 mm; checked by model.py --check
Aligning moment per wheel at 0.2 g, loaded, model | 7.856 | N m | centres the steering
Aligning moment per wheel at 0.2 g, loaded, 30 mm fork | 6.734 | N m | centres the steering
Aligning moment per wheel at 0.2 g, loaded, 40 mm fork | 8.978 | N m | centres the steering
Self-centring torque at the column, both wheels, 0.2 g, loaded | 15.71 | N m | 1:1 linkage
as a force at each grip (300 mm half-bar, two hands) | 26.19 | N
Self-centring torque at the column, rider only, 0.2 g | 5.068 | N m
Reference: same fork fitted as sold (crown forward), trail | -35 | mm | pulls into the turn; not allowed
Front wheel drop (flop) when steered, vertical axis | 0 | mm | no lift or fall of the front with steering
Gravity self-centring (needs caster or kingpin inclination) | 0 | N m
Contact patch swing across at full lock (inner wheel) | 22.5 | mm | the rear of the inner tyre swings in
Bed rail at the tyre notch: depth of plate left | 55 | mm | notch 1200 to 1305 mm from the rear axle
Bed rail at the tyre notch: bending moment per rail, dynamic | 58.98 | N m
Bed rail at the tyre notch: bending stress | 39 | MPa | yield 235 MPa
Tipping threshold, loaded, any lock | 0.4189 | g | CoM 1.08 m ahead, 0.73 m high
speed at threshold on a 5 m radius, loaded | 16.32 | km/h
Tipping threshold, rider only, any lock | 0.2419 | g | CoM 0.69 m ahead, 0.81 m high
speed at threshold on a 5 m radius, rider only | 12.4 | km/h
Tipping threshold, rider only, 90 kg, any lock | 0.2313 | g | CoM 0.67 m ahead, 0.83 m high
speed at threshold on a 5 m radius, rider only, 90 kg | 12.12 | km/h
Tipping threshold, 90 kg rider and 138 kg cargo, any lock | 0.3973 | g | CoM 1.05 m ahead, 0.75 m high
speed at threshold on a 5 m radius, 90 kg rider and 138 kg cargo | 15.89 | km/h
tip-up speed at full lock, loaded | 11.2 | km/h | CoM path radius 2.36 m
tip-up speed at full lock, rider only | 8.234 | km/h | CoM path radius 2.20 m
Cornering-speed label, empty, full-lock turns (70 % of tip-up lateral acceleration, rounded down) | 6 | km/h
Cornering-speed label, empty, 10 m radius turns (same rule) | 14 | km/h
Ballast low in the box for 0.30 g rider only (sensitivity) | 30 | kg
Rear axle load, loaded (static) | 694.1 | N
Upper stay strip force (both plates, static) | -1926 | N | negative = compression
Lower stay strip force (both plates, static) | 1532 | N
Compression per plate, dynamic x2.5 | 2407 | N
Narrowest upper stay strip (edge to window) | 100.4 | mm
Strip buckling load, if unbraced from axle to seat node | 1267 | N | L = 608 mm, pinned ends
safety factor on dynamic compression, if unbraced from axle to seat node | 0.5261
Strip buckling load, braced by the stay bridge (300 mm) | 5201 | N | L = 300 mm, pinned ends
safety factor on dynamic compression, braced by the stay bridge (300 mm) | 2.161
Safety factor with the TRL 2 style 55 mm strip, braced | 1.184
Static net stress in upper strip at an M8 hole | 3.493 | MPa
Dynamic net stress in upper strip | 8.734 | MPa
Rear frame and rider mass | 117.5 | kg
Roll moment at the kingpin, 0.5 g lateral | 516.2 | N m
Spine shear stress, open twin plates (TRL 2) | 573.6 | MPa | yield in shear about 136 MPa
Spine shear stress, closed box with covers (TRL 3) | 9.29 | MPa
Shear flow on each cover edge | 27.87 | N/mm
Tab bearing stress, 10 tabs per edge over 280 mm of closed box (3 x 3 mm bearing face) | 86.76 | MPa
Spine torsional stiffness GJ, open | 218.7 | N m2
Spine torsional stiffness GJ, closed | 1.957e+05 | N m2
Vertical shear at the bed-to-spine joint, loaded (static) | 458.1 | N | negative = bed lifts the rear frame
Pitch moment at the bed-to-spine joint, loaded (static) | 97.33 | N m
Spine bending moment at the front node (dynamic plus 0.5 g braking) | 788.2 | N m
Spine bending stress | 15.5 | MPa
Front load, dynamic | 5612 | N
Axle beam bending stress (twin 3 x 120 mm, UDL over 566 mm) | 36.96 | MPa
Knuckle load per wheel, dynamic | 2806 | N
Knuckle post cantilever stress at its root (two plates, 120 mm deep) | 15.98 | MPa
Lower knuckle collar plate: cup flange radius against the plate supports (half span) | 2.5 | mm | the flange bears on the plate within 2.5 mm of the transverse plates' edges, so the plate is not bent
Knuckle post column bending moment | 321.3 | N m
Knuckle post column stress (closed 45 x 50 mm box of 3 mm plate) | 40.64 | MPa
Column stress if the cheeks were left out (two plates only) | 158.6 | MPa
Knuckle headset axial load, dynamic | 2806 | N
Joint couple at the head tube, 0.5 g roll, 150 mm head tube (TRL 3, v0.1) | 3441 | N
Joint couple at the head tube, 0.5 g roll, 200 mm head tube | 2581 | N | carried by the cups into the yokes and by the yokes' tabs into the spine side plates
Bearing stress, roll couple on one yoke's two tabs (16 x 3 mm side faces) | 26.89 | MPa
M8 8.8 preload at 25 N m | 1.56e+04 | N
Slip load per bolt per faying face (mu 0.20) | 3120 | N
Stay node force per plate, dynamic | 2407 | N
Bolts per plate per node for no slip (1 face; spacer stack in series) | 1
Bearing resistance of 3 mm plate at one M8 bolt | 1.728e+04 | N
Bearing utilisation if the node slips onto 2 bolts | 6.965 | %
Stress range, routine road cycle (+/- 0.5 g) | 3.493 | MPa
Stress range, pothole cycle (to 2.5 g and back) | 10.48 | MPa
Constant-amplitude fatigue limit, 90 MPa detail | 66.33 | MPa
Cycles in 5 years (300 days, 20 km, 1 per 10 m) | 3e+06
Proof load, twice rated cargo (148 kg) (R2) | 2904 | N
Axle beam stress under proof load | 19.13 | MPa
Kinetic energy at 15 km/h, gross | 2.6 | kJ
Deceleration to stop in 6 m (no reaction time) | 1.447 | m/s2
Deceleration to stop in 6 m with 0.5 s reaction | 2.216 | m/s2
Drum torque needed per wheel, equal share | 36.69 | N m
Tyre grip needed at the front pair alone | 0.1931 |  | friction coefficient
Parking force on a 10 % grade | 292.4 | N
Drum torque per front wheel to park (latch on the front pair) | 37.14 | N m
Brake power, 10 km/h down a 5 % grade | 274.1 | W
Drum heat capacity per wheel (0.35 kg iron, 0.30 kg aluminium) | 431 | J/K
Steady drum temperature rise (hA 0.5 W/K) | 182.8 | K
Time to a 100 K rise | 11.38 | min
Descent length to a 100 K rise at 10 km/h | 1.897 | km
Assembly work content | 6.258 | person-h
Elapsed time, two people (70 % parallel) | 4.068 | h | R7 target 4 h
Bolts disturbed to replace one spine side plate | 30
Time to replace one spine side plate (0.75 min per bolt each way, 15 min, 20 min for the column and bottom bracket) | 80 | min | R14 target 90 min for the spine side plates only
Bolts disturbed to replace one knuckle post plate (both collar plates come off) | 12
Time to replace one knuckle post plate (0.75 min per bolt each way, 15 min, 20 min for wheel, fork and cups) | 53 | min | R14 target 60 min for a knuckle post plate (2026-10-02)
Margin under R14 for a knuckle post plate | 7 | min
Unprotected loss, 5 years at the C3 first-year upper rate (both faces) | 0.2627 | mm | bilogarithmic law, exponent 0.6 assumed
Unprotected loss, 5 years at the C4 first-year upper rate (both faces) | 0.4202 | mm | bilogarithmic law, exponent 0.6 assumed
BOM lines | 15
Base prototype, pedal only (bom.csv) | 736 | USD | budget 800
Budget margin | 64 | USD
Optional assist kit, route C, excluding the SwapCell pack | 300 | USD
Cut length per frame (estimate) | 57.31 | m
Steel, one full sheet at 1.0 USD/kg | 73.59 | USD
Laser cutting at 0.30 USD/m (volume rate, assumed) | 17.19 | USD
Bought parts at 65 % of prototype retail | 328.9 | USD
Production cost at 100 units (parts, cutting, 15 USD assembly labour) | 470.7 | USD | R18 target 300

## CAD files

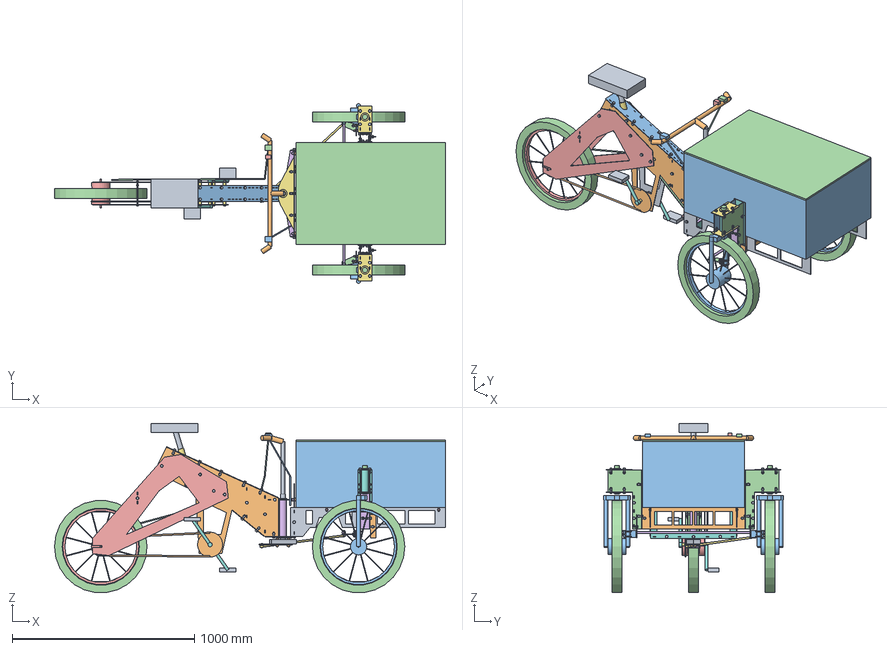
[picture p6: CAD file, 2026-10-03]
cad/step/flattrike-assembly.step
2146.0 x 985.9 x 928.1 mm

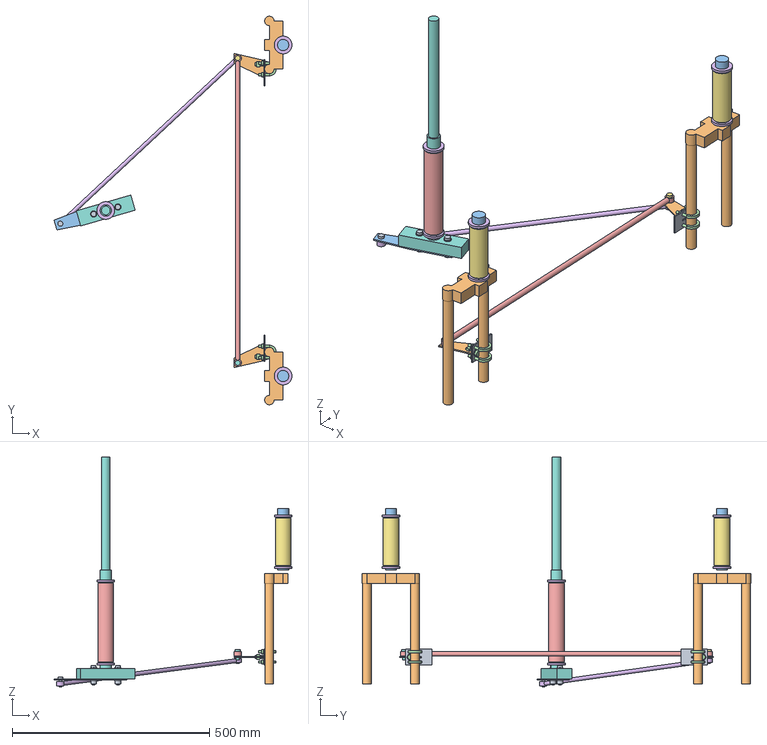
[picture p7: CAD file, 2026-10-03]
cad/step/flattrike-frame.step
603.9 x 986.0 x 583.0 mm

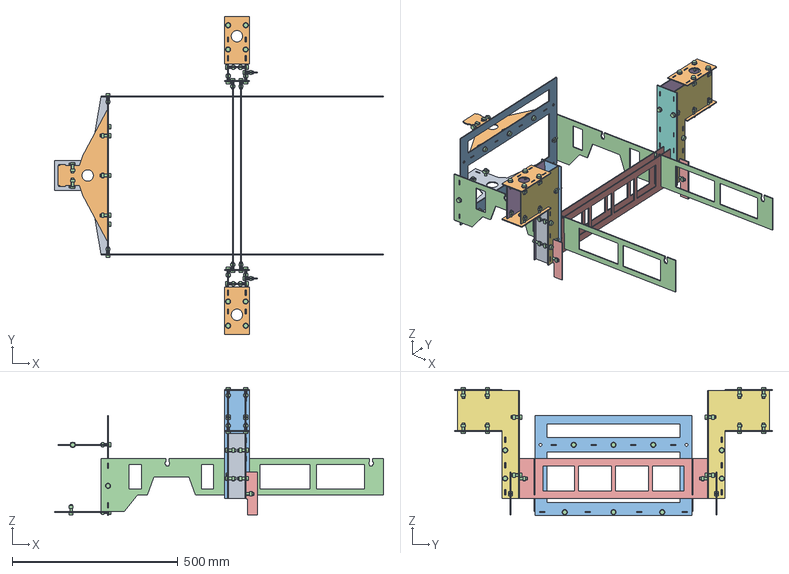
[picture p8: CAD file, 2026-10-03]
cad/step/flattrike-front-bed.step
992.0 x 960.0 x 386.9 mm

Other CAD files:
cad/stl/flattrike-assembly.stl
cad/stl/flattrike-frame.stl
cad/stl/flattrike-front-bed.stl

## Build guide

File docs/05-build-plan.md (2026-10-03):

---
doc_id: FTK-BLD-001
title: FlatTrike prototype build plan
project: FlatTrike
doc_type: Build plan
version: "0.5"
status: Draft
date: '2026-10-03'
author: Amish Chadha
license: CERN-OHL-S-2.0
revisions:
  - version: "0.1"
    date: '2026-10-01'
    author: Amish Chadha
    change: First build plan, with pictures by component and step; design made constructable (FTK-DDR-003)
  - version: "0.2"
    date: '2026-10-01'
    author: Amish Chadha
    change: Budget treated as a value-engineering target
  - version: "0.3"
    date: '2026-10-02'
    author: Amish Chadha
    change: "Decisions of 2026-10-02: rated load 148 and 138 kg and 72 kg empty-mass limit; steering lock stops and steering geometry study added to safety stop S6 and the steering check. Pictures unchanged"
  - version: "0.4"
    date: '2026-10-02'
    author: Amish Chadha
    change: "Steering lock stops carried into the design: new making sketch FTK-DWG-124 and section 3.24; knuckle post plate, clamp plate, joint and step pictures 13 to 21 redrawn; figures from 37 renumbered; masses, bolt counts and turning circle from FTK-CAL-001 v0.6"
  - version: "0.5"
    date: '2026-10-03'
    author: Amish Chadha
    change: "Knuckle forks turned round to trail (decided by Amish 2026-10-03): fork specification, bed rail tyre notch, knuckle post plate lip, shorter steering arms, clamp plates and lock stops; making sketches FTK-DWG-112, 114, 116, 118, 119 and 124, joints 8, 9 and 11, steps 11 to 21 and the overview redrawn; S6 and the steering check updated; figures from FTK-CAL-001 v0.7"
---

# FlatTrike prototype build plan

**Plan, not yet built.** How to build the first proof-of-concept prototype, component by component. Building and testing to it is TRL 4 work. Decisions still to be made are kept in the design decisions register ([docs/06-design-decisions.md](06-design-decisions.md)), not here.

## 1. What you are building

Figure 1. Every component, pulled apart and numbered in build order

*Figure 1. Every component pulled apart and numbered in build order. The bolts that join the plates are left out of this picture.*

The prototype is a front-loading cargo tricycle: a steel frame of 37 flat plates, cut from one 1,250 x 2,500 x 3 mm sheet of mild steel by a laser or waterjet shop, carrying a plywood box over two steered 20 in front wheels, with the rider over a 20 in rear wheel with a 3-speed hub. Figure 1 shows the 26 groups of parts in the order you make or fit them. The plates join by tabs that sit in slots, held closed by M8 bolts whose locknuts sit in windows cut in the plates; nothing is welded or bent. The other made parts are 78 spacer washers cut from the same sheet, four spacer tubes and three tube lengths sawn from bought steel tube, a bought fork cut down for the steering column, and a plywood box made by a carpenter. Everything else is bought bicycle parts: wheels, forks, headsets, bottom bracket, drivetrain, brakes, seatpost, saddle and bars. The work is deburring cut plate, sawing and facing tube, drilling a fork crown and the box, pressing headset cups, and ordinary bicycle mechanics. The parts cost about $736, from the bill of materials, against a value-engineering target of $800.

> **Safety:** The finished trike is a vehicle of about 300 kg loaded with exposed moving parts. Laser-cut edges are sharp: deburr every plate and wear cut-resistant gloves when handling them. Keep fingers clear of the steering linkage, wheels and chain whenever the trike is moved. Do not ride it, load it or let anyone else use it until the safety stops of section 6 are passed, and never on a public road before the frame's strength is verified.

## 2. What changed to make it buildable

The concept showed what the trike does, but its plates were drawn as loose shapes with no joints, and checking the model found parts that cut through each other, a steering linkage that locked and steering arms that hit the frame. Each change below keeps what the trike does. All of them are recorded in decision record FTK-DDR-003, accepted by Amish on 2026-10-02.

*Table 1. Changes from the concept.*

| Component | The concept had | The buildable design has | Why |
| --- | --- | --- | --- |
| Every plate joint | No joints drawn; spine covers exactly as wide as the spine | Tabs in slots, with M8 bolts into slots cut in the plates' edges where a locknut sits in a window (Figure 4); covers 12 mm wider than the spine each side | The tabs carry the load, the bolts hold the joint closed, and every bolt hole has plate round it |
| Stay-to-spine bolts | Two of the four bolts in a lightening window; nothing between the spine plates | Bolts moved onto solid plate; a spacer tube inside the spine on each (Figure 19) | Every bolt clamps plate, and the spine cannot be squeezed |
| Rear dropouts | A closed hole: the wheel could not go in | An open slot 10 mm wide from the stays' rear edge (Figure 16) | The wheel slides in and pulls back to tension the chain |
| Chain | On the rider's left | On the right, 44 mm from the centre | Standard parts are right-hand drive |
| Bottom bracket | Shell through both plates, collars not drawn | Shell between the plates; the cups clamp the plates (Figure 14) | Uses the bought cups as the clamp |
| Seatpost | Stood in the open spine | Bought seat tube through two cut saddles, with shaft collars (Figure 6) | Something to clamp the seatpost in |
| Head tube | Clamp plates cut through the spine; lower yoke where the steering fork crown is | The yokes are the clamp plates; the headset cups hold them to the tube's ends (Figure 13) | Two fewer plates, and the head tube load goes straight into the spine |
| Steering column and linkage | No bearing seat; a drop arm with no fixing; a linkage that locked after about 10° of right turn | A cut-down forged-crown fork; the drop arm bolted under its crown, parallel to the left steering arm (Figures 28 and 29) | Steers 40° each way; the handlebar turns as far as the left wheel |
| Steering arms | No fixing; they swung into the knuckle posts at lock | Below the posts, clamped to the inboard fork leg by two U-bolts (Figure 36); posts and axle beams start 60 mm higher | Clears the frame from lock to lock |
| Knuckle posts | Collar plates bent by the wheel load; flush corners with no room for bolts | Post plates 25 mm either side of the head tube, so the load goes straight into them (Figure 30); proper slots at every corner (Figure 26) | Strong enough and buildable |
| Bulkhead, rails, axle beams | Yoke met a window; rails and beams passed through each other | Bulkhead window split; rails extended; halving joints (Figure 23) | Every joint has plate round it |
| Steering lock | Set only by the tyres' clearance under the box | A lock stop under each knuckle post that the steering arm clamp plate meets at 40° (Figure 37; decided on 2026-10-02) | The wheels cannot be turned into the box or the posts |
| Front forks | A fork fitted as sold, offset forward on a vertical head tube: negative trail, so the steering would pull into turns | Straight-leg forks with 30 to 40 mm offset, each fitted turned round so the wheel trails its steering axis by 35 mm; a tyre notch in each bed rail and a trimmed knuckle post lip for the swinging tyre and crown (decided on 2026-10-03) | The steering returns to straight ahead by itself |
| Box | No fixing | Eight bolts to the bed, standing 9 mm off the bulkhead on spacer washers (Figure 39) | Clears the bolt heads behind it |

The changes add 1.4 kg, the lock stops with their longer clamp plates about 0.5 kg more, and turning the forks to trail takes 0.2 kg off: the empty trike is about 71.6 kg. The cargo is therefore rated at 148 kg with a rider up to 80 kg and 138 kg with a rider up to 90 kg, keeping the 300 kg class, and the empty-mass limit is 72 kg; the final load label is set from the weighed trike.

## 3. Making the components

Make and check each component before the assembly step that needs it. Sizes are in millimetres. "Left" and "right" are as the rider sits. Every plate is cut by the laser or waterjet shop from the model's outlines, with all its tabs, slots, holes and T-slots in the same pass; your work on a plate is to deburr it, check it and mark it. Cutting tolerance should be 0.1 mm on slot widths; drawings do not carry tolerances before TRL 4.

Three words are used throughout:

- A **tab** is a 12 or 16 mm long tongue on a plate's edge, 3 mm proud, that fits a **slot** (3.4 mm wide) in the plate it meets.
- A **T-slot** is a cut 9 mm wide and 23 mm deep into a plate's edge, with a 13.6 x 8.4 mm window 10 mm in. An M8 all-metal locknut drops into the window and cannot turn; an M8 x 25 bolt through the other plate screws into it.
- **Deburr** means file or scrape every cut edge, slot and hole until no burr or sharp corner is left, then break the outside corners of every plate to about 1 mm.

### 3.1 Spine side plates (make 2)

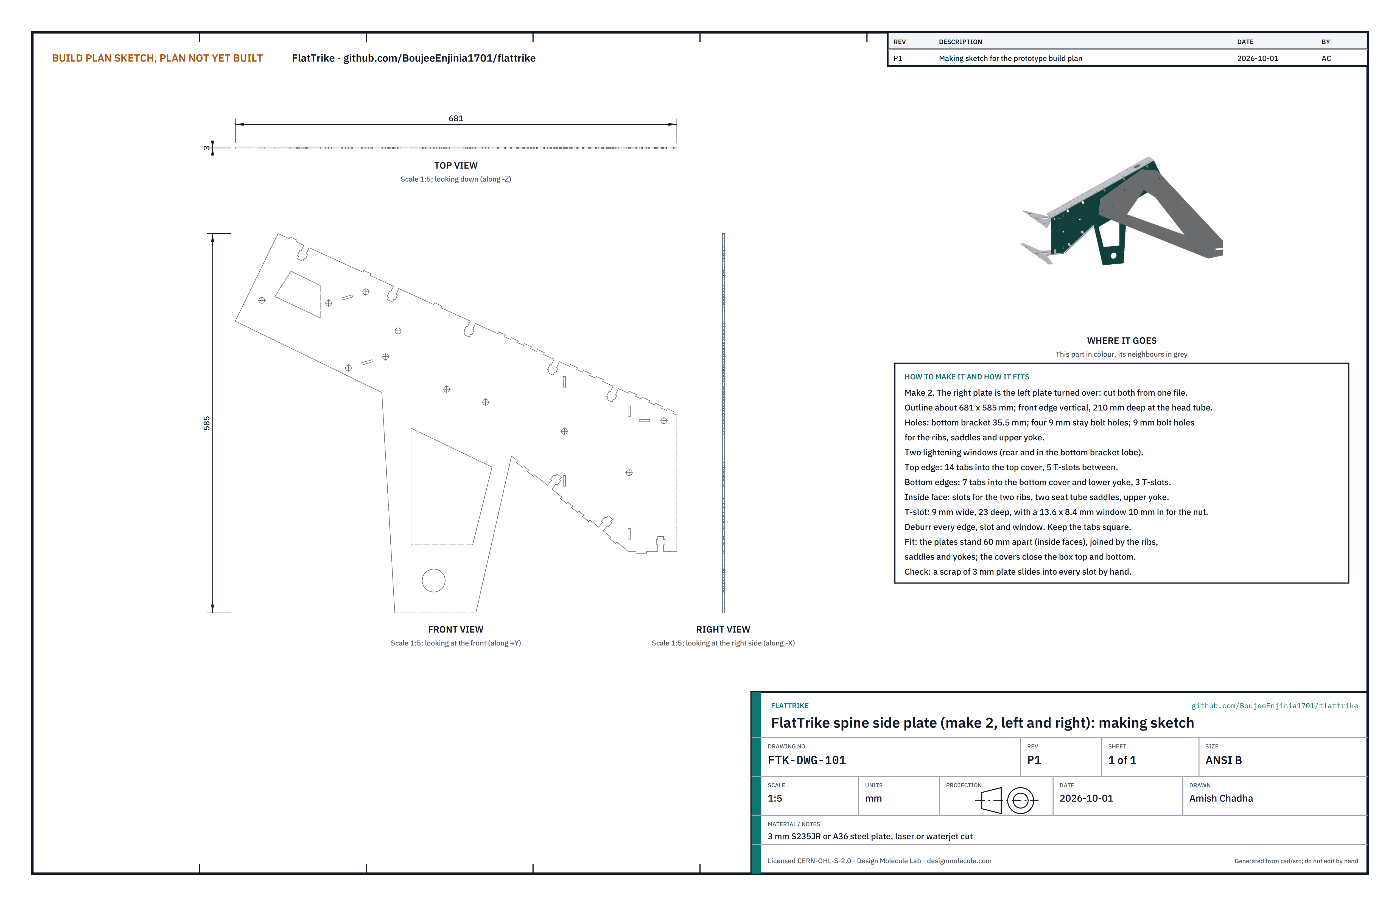
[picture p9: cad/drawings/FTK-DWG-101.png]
Figure 2. Making sketch of the spine side plate


*Figure 2. Spine side plate making sketch (FTK-DWG-101).*

**What it is and what it is made from.** The two big plates that form the walls of the spine, the backbone from the seat to the head tube, with a lobe down to the bottom bracket. 3 mm S235JR or A36 steel, about 681 x 585 mm each.

**How to make it.**

1. Have both cut from the same outline; the right plate is the left one turned over.
2. Deburr. Check every slot by sliding a 3 mm offcut into it by hand.
3. Mark each plate's inside face and "L" or "R" with a paint pen.

**How it fits the parts next to it.** The plates stand 60 mm apart, inside face to inside face. The two ribs, two seat tube saddles and the upper yoke stand between them with their tabs in the plates' slots (Figure 4); the top and bottom covers lie on their edges, with the plates' edge tabs up or down through the covers' slots (Figure 9). The bottom bracket fits through the 35.5 mm holes (Figure 14) and the stays bolt on outside them (Figure 19).

**Check before moving on.** Laid one on the other, inside faces together, the two plates match all round within 1 mm.

### 3.2 Spine ribs (make 1 of each)

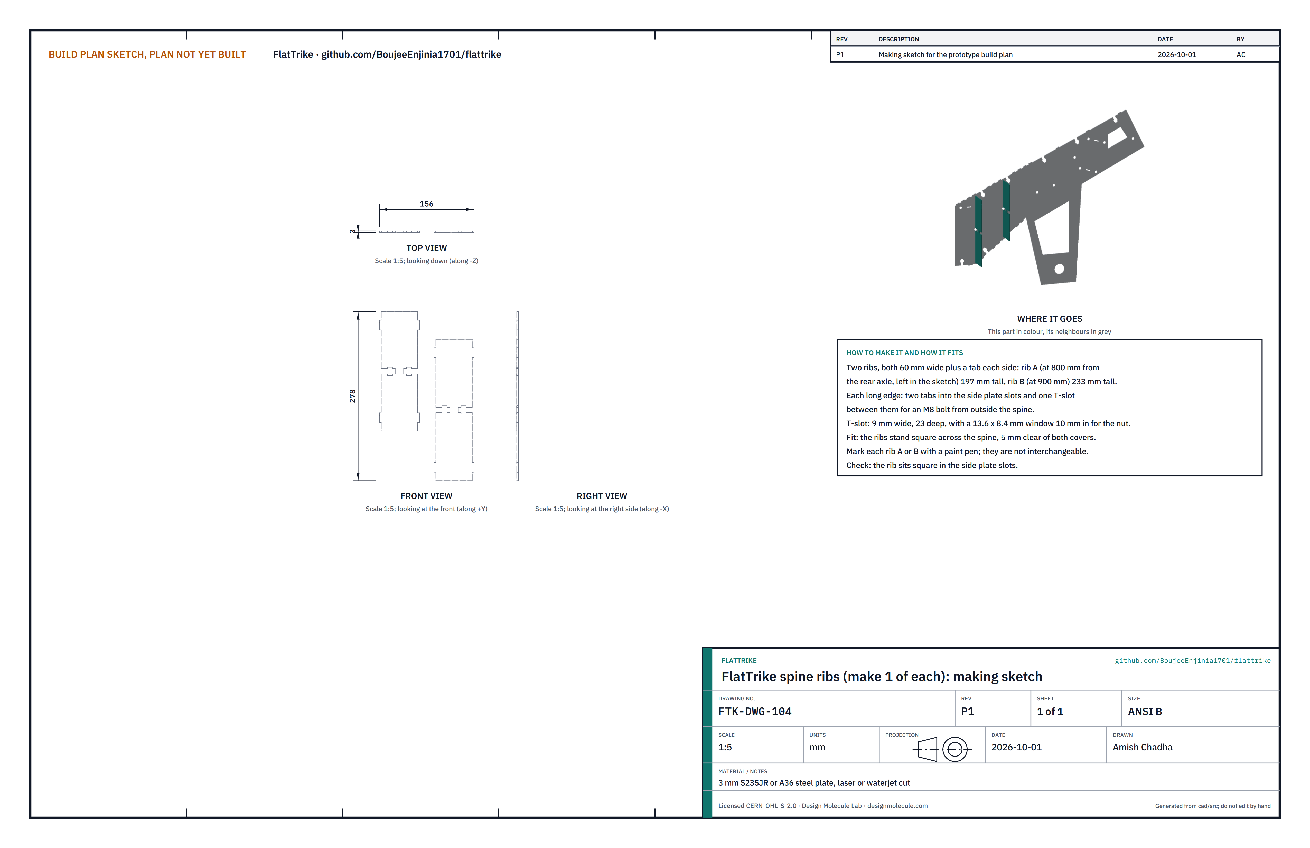
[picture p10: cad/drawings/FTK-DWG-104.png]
Figure 3. Making sketch of the spine ribs


*Figure 3. Spine ribs making sketch (FTK-DWG-104): rib A, 197 mm tall, on the left; rib B, 233 mm tall, on the right.*

**What it is and what it is made from.** Two cross plates that keep the spine box square, 800 and 900 mm ahead of the rear axle. 3 mm steel, 60 mm wide plus a tab each side.

**How to make it.** Deburr, then mark A and B: they are different heights and not interchangeable.

**How it fits the parts next to it.**

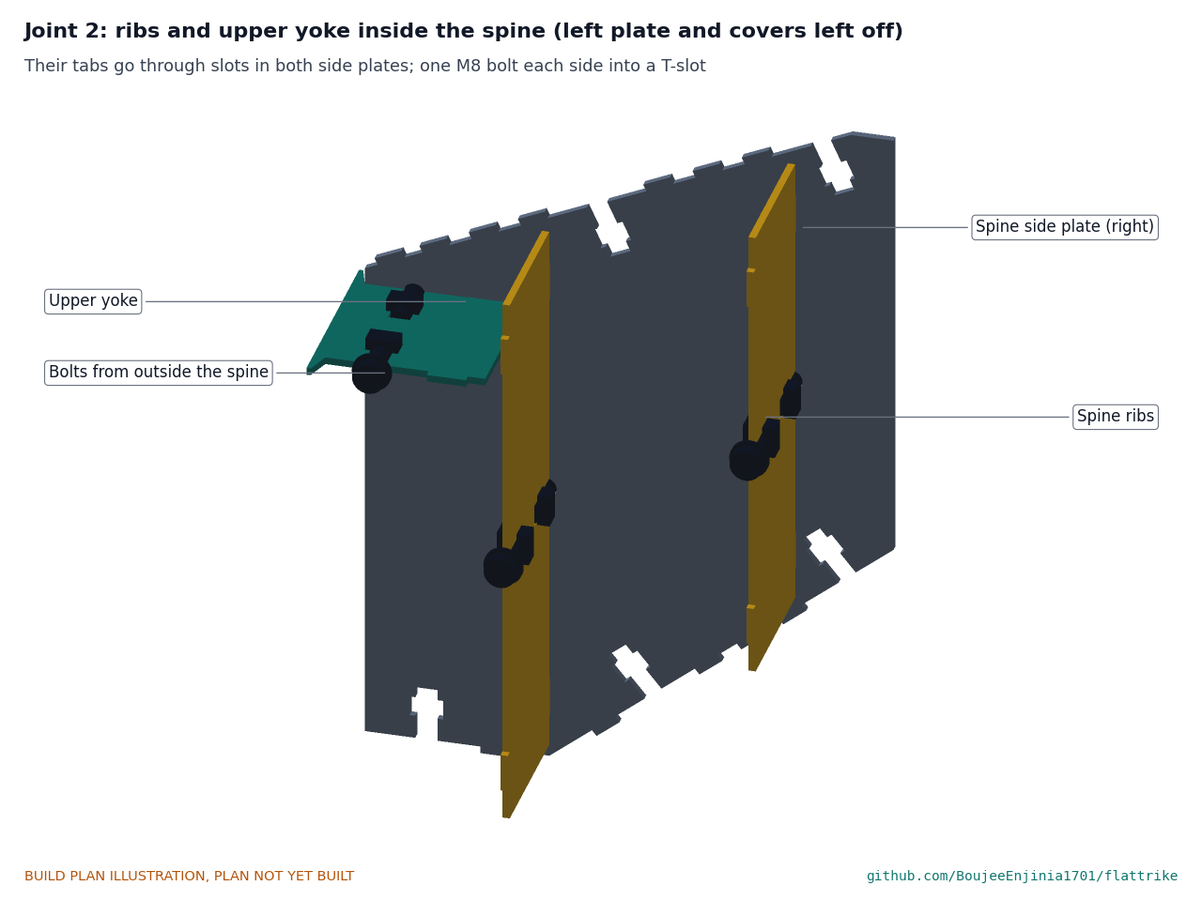
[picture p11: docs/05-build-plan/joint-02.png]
Figure 4. Joint 2: ribs and upper yoke inside the spine


*Figure 4. Each rib's edges carry two tabs into the side plates' slots and a T-slot between them; an M8 bolt comes in from outside the spine.*

Each rib stands square across the spine, 5 mm clear of both covers.

**Check before moving on.** The rib sits square in the slots of a side plate laid flat.

### 3.3 Seat tube saddles (make 2)

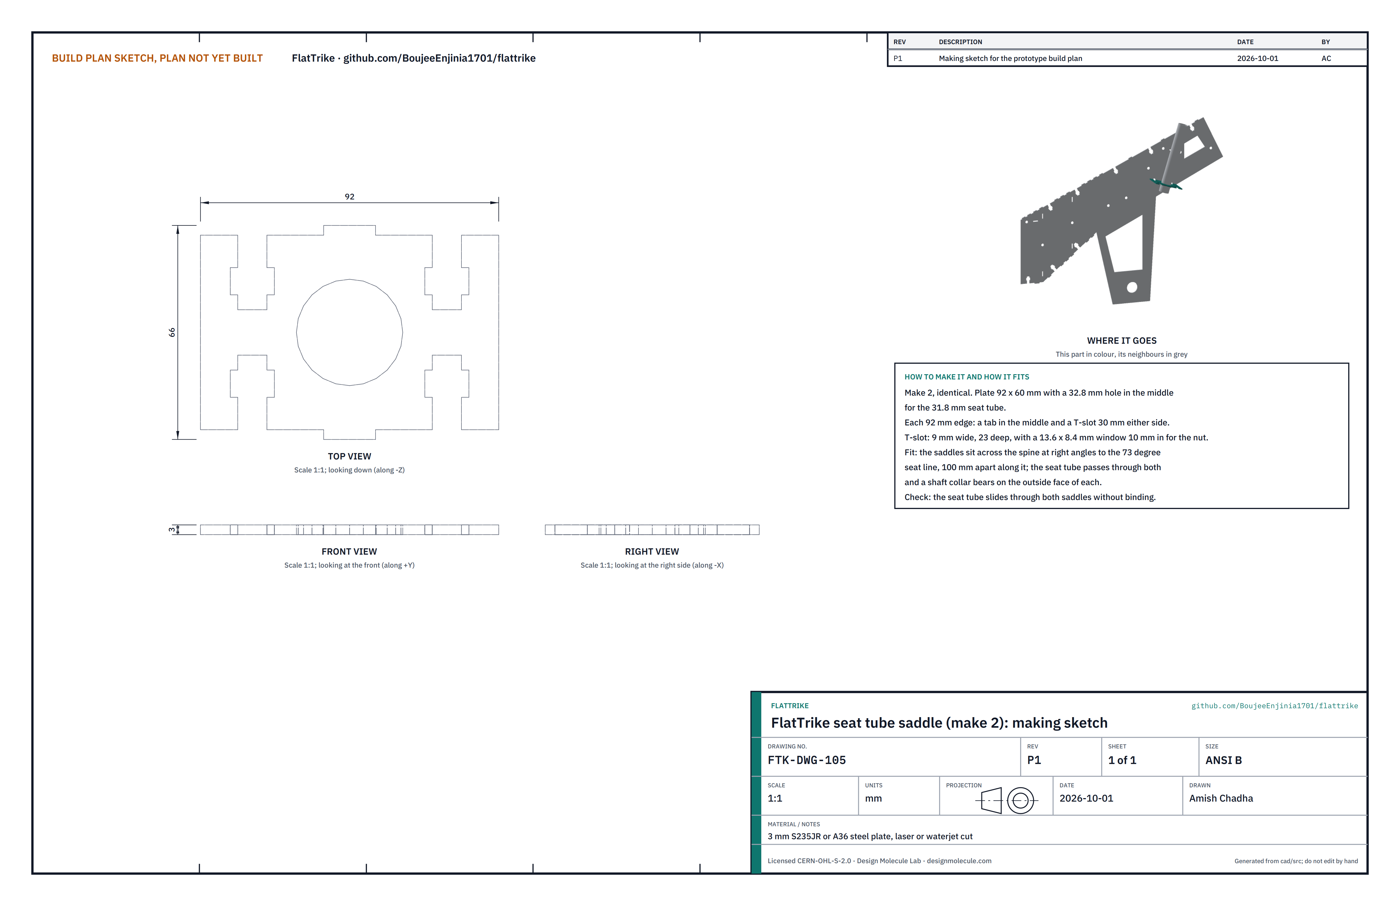
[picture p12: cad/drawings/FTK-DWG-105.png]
Figure 5. Making sketch of the seat tube saddle


*Figure 5. Seat tube saddle making sketch (FTK-DWG-105).*

**What it is and what it is made from.** Two cross plates that hold the seat tube, one 600 mm and one 700 mm up the seat line. 3 mm steel, 92 x 60 mm with a 32.8 mm hole in the middle.

**How to make it.** Deburr the hole carefully: the seat tube must slide through without catching.

**How it fits the parts next to it.**

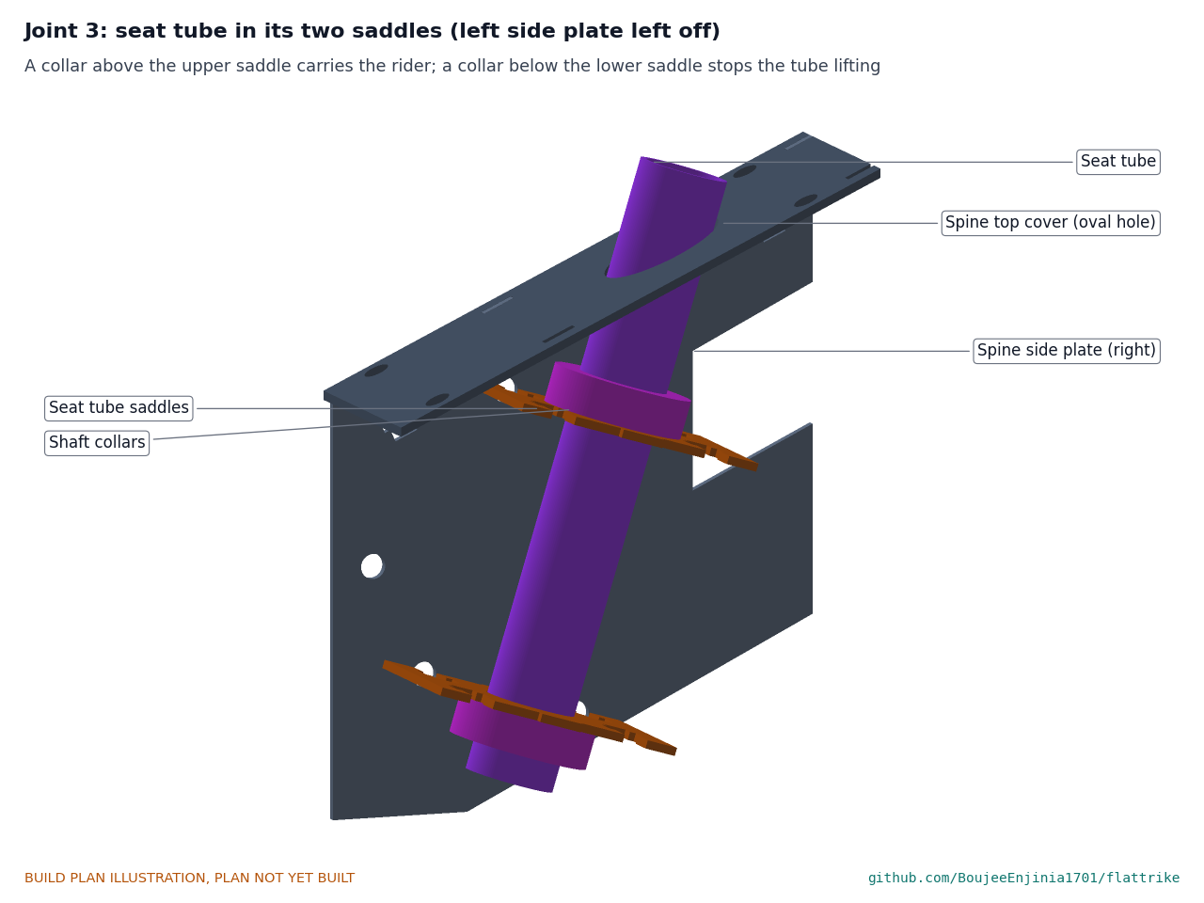
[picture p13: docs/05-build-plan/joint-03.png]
Figure 6. Joint 3: seat tube in its saddles


*Figure 6. The saddles sit across the spine at right angles to the 73° seat line, each held by a tab and two bolts on each side. A collar above the upper saddle carries the rider; a collar below the lower saddle stops the tube lifting.*

**Check before moving on.** A length of the seat tube slides through both saddles held in line.

### 3.4 Upper yoke

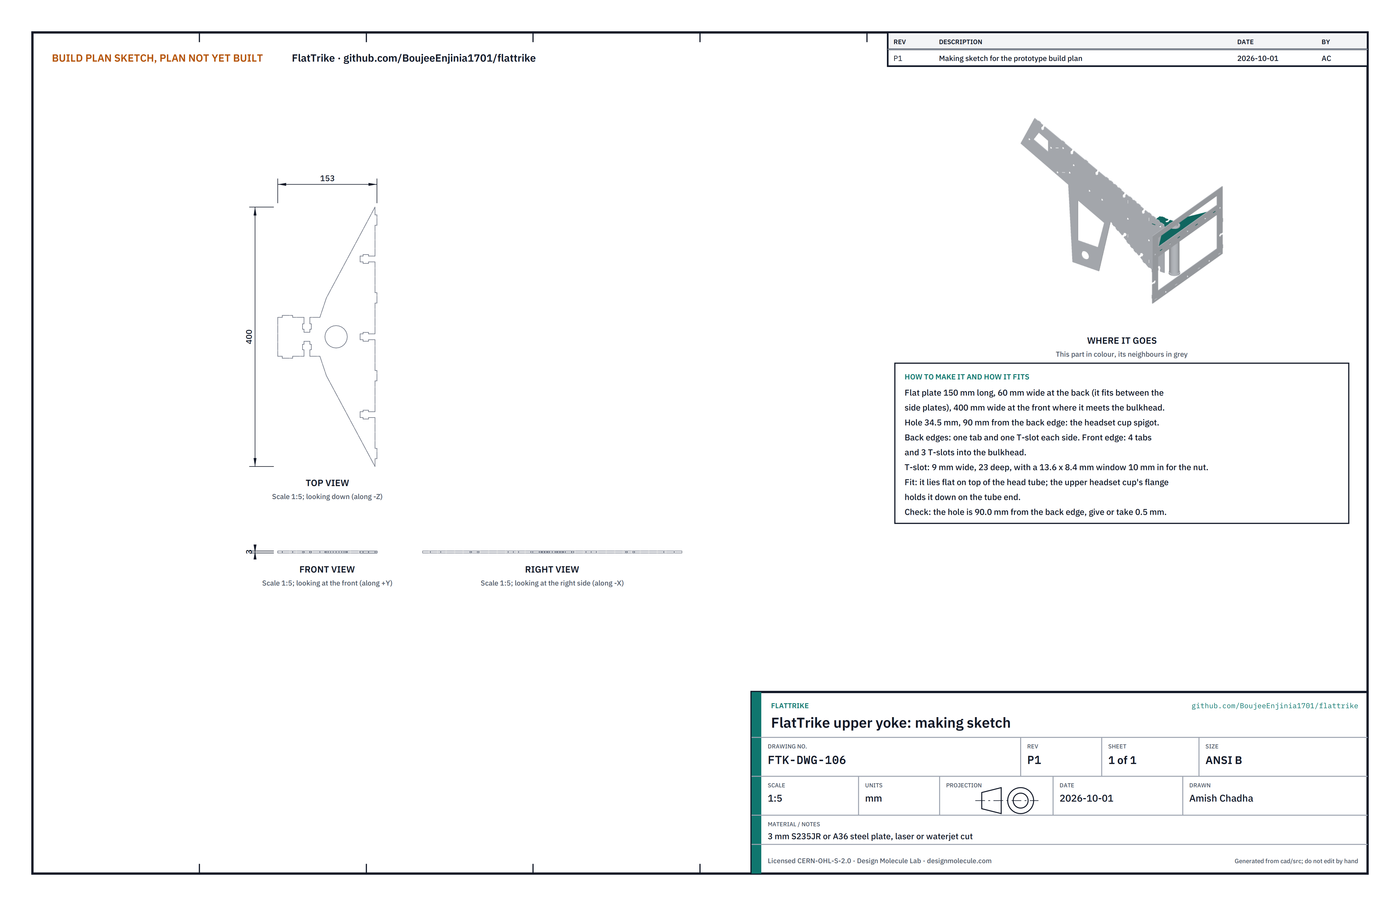
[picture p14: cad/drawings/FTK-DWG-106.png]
Figure 7. Making sketch of the upper yoke


*Figure 7. Upper yoke making sketch (FTK-DWG-106).*

**What it is and what it is made from.** The plate on top of the head tube that ties it to the spine and the bed. 3 mm steel, 150 mm long, 60 mm wide at the back and 400 mm at the front, with a 34.5 mm hole 90 mm from the back edge.

**How to make it.** Deburr; check the hole is round and burr free, because a headset cup passes through it.

**How it fits the parts next to it.** Its back end stands between the spine plates, a tab and a bolt each side (Figure 4); the head tube's top end bears under it (Figure 13); its front edge's tabs go into the bulkhead (Figure 21).

**Check before moving on.** The hole is 90.0 mm from the back edge, give or take 0.5 mm.

### 3.5 Spine top cover

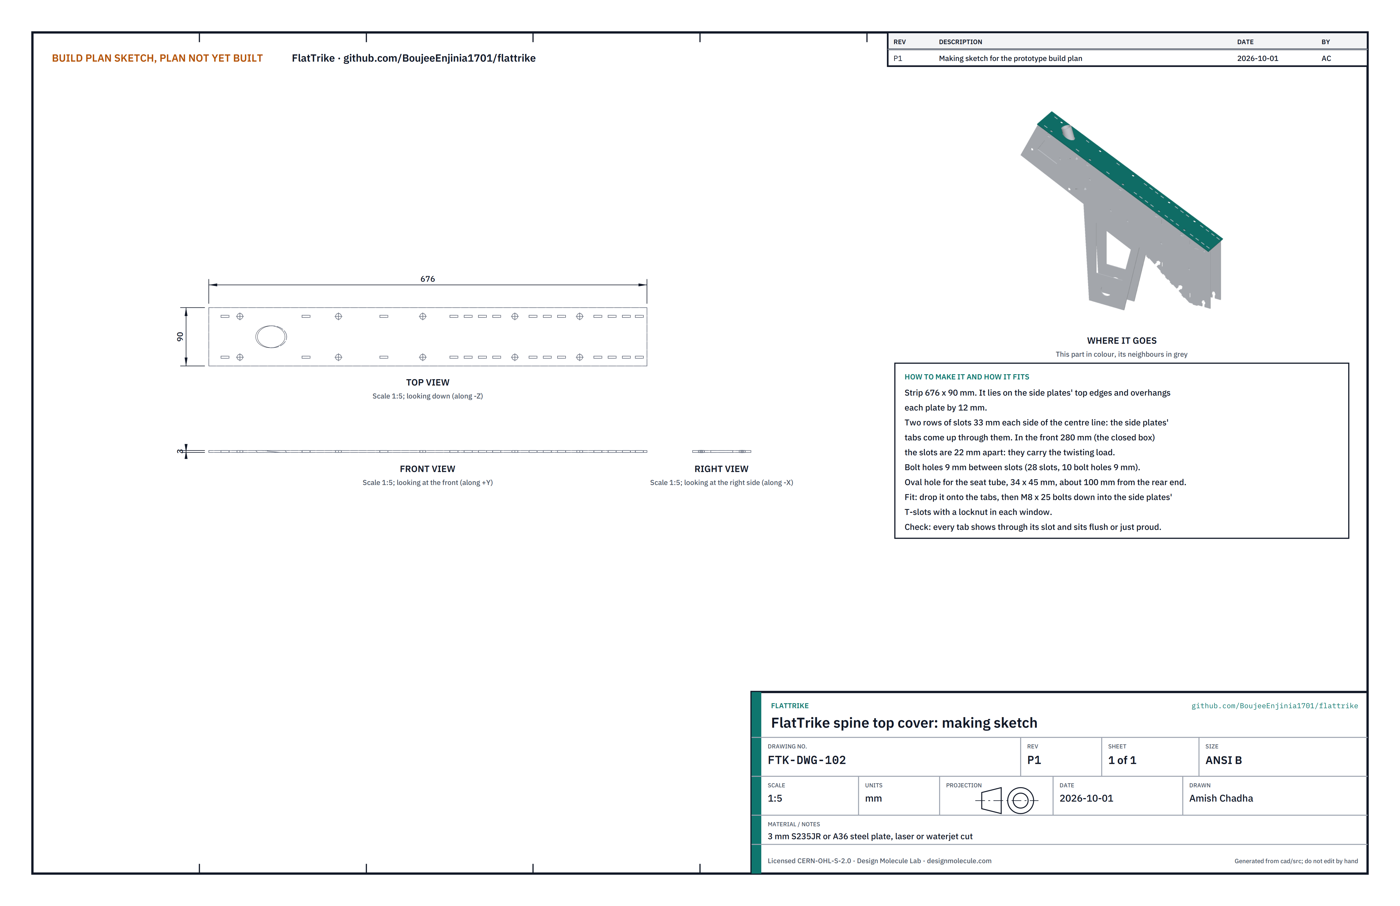
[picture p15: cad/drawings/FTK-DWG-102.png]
Figure 8. Making sketch of the spine top cover


*Figure 8. Spine top cover making sketch (FTK-DWG-102).*

**What it is and what it is made from.** The strip that closes the top of the spine box. 3 mm steel, 676 x 90 mm, with two rows of slots and an oval hole for the seat tube near its rear end.

**How to make it.** Deburr; check the oval hole passes the seat tube at its slope.

**How it fits the parts next to it.**

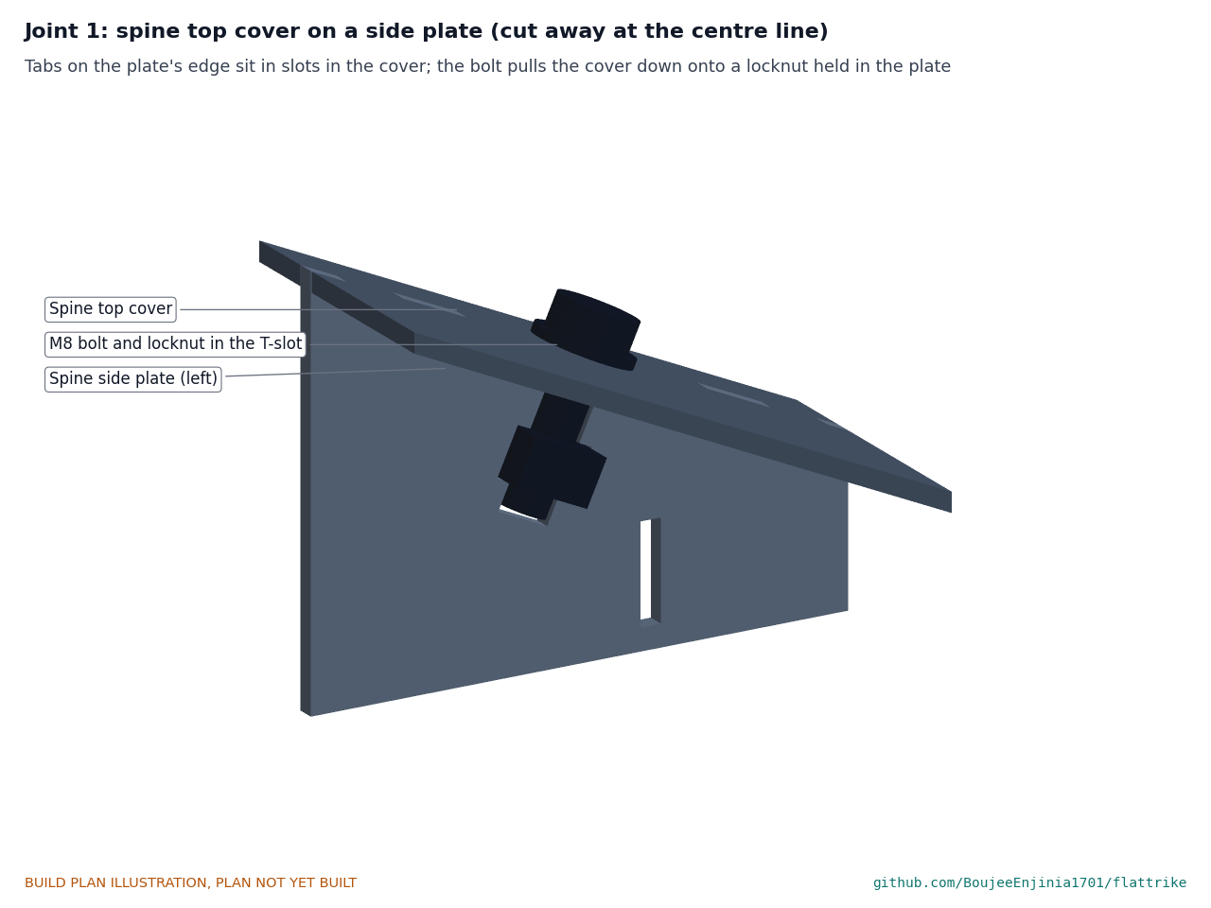
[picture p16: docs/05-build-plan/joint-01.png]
Figure 9. Joint 1: top cover on a side plate


*Figure 9. The side plate's tabs come up through the cover's slots; the bolt goes down through the cover into the plate's T-slot and its locknut.*

The cover overhangs each side plate by 12 mm. In its front 280 mm, where the spine is a closed box, the slots are 22 mm apart: they carry the twisting load from the rear frame.

**Check before moving on.** Every tab shows through its slot when the cover is dropped on.

### 3.6 Spine bottom cover

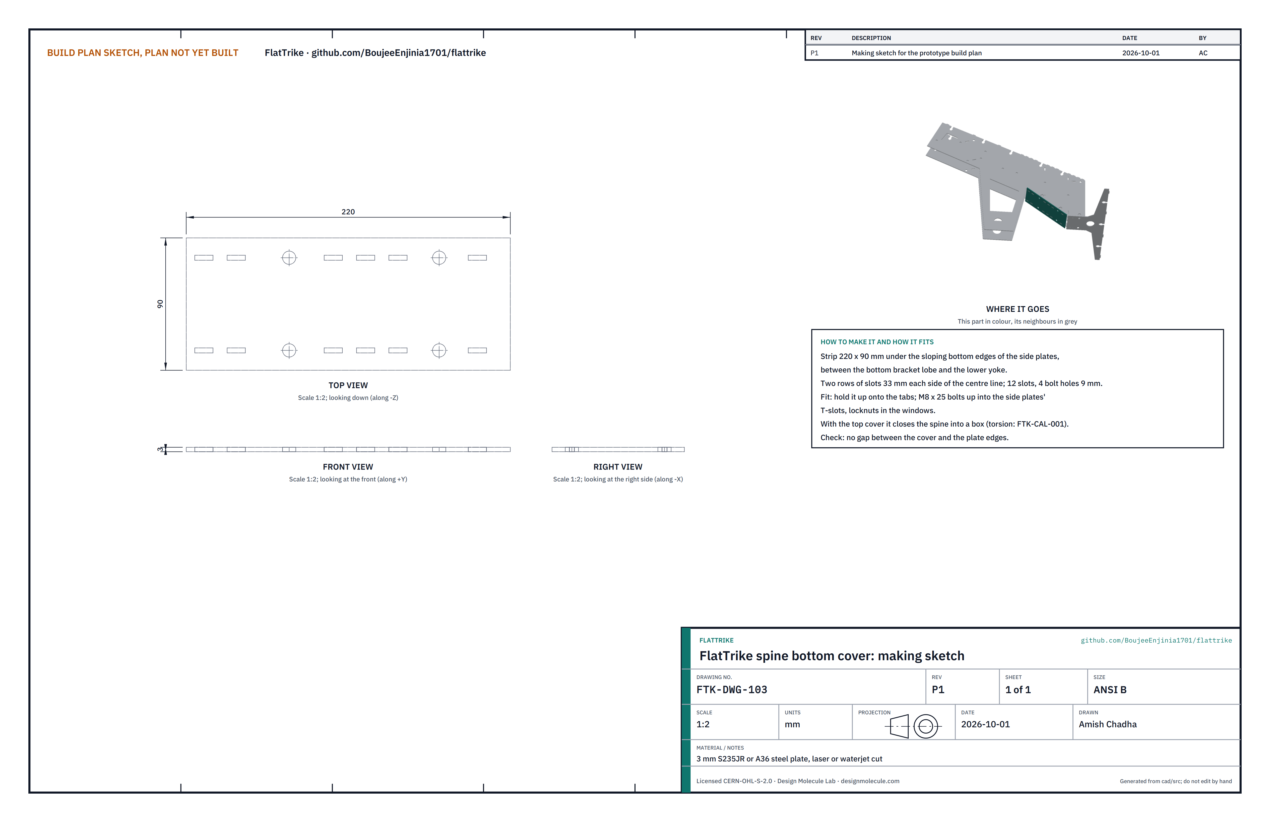
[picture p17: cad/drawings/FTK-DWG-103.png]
Figure 10. Making sketch of the spine bottom cover


*Figure 10. Spine bottom cover making sketch (FTK-DWG-103).*

**What it is and what it is made from.** The strip that closes the bottom of the spine box between the bottom bracket lobe and the lower yoke. 3 mm steel, 220 x 90 mm.

**How to make it.** Deburr.

**How it fits the parts next to it.** As the top cover (Figure 9), upside down: the plates' bottom-edge tabs go down through it and the bolts go up.

**Check before moving on.** No gap between the cover and the plate edges when it is held up.

### 3.7 Lower yoke

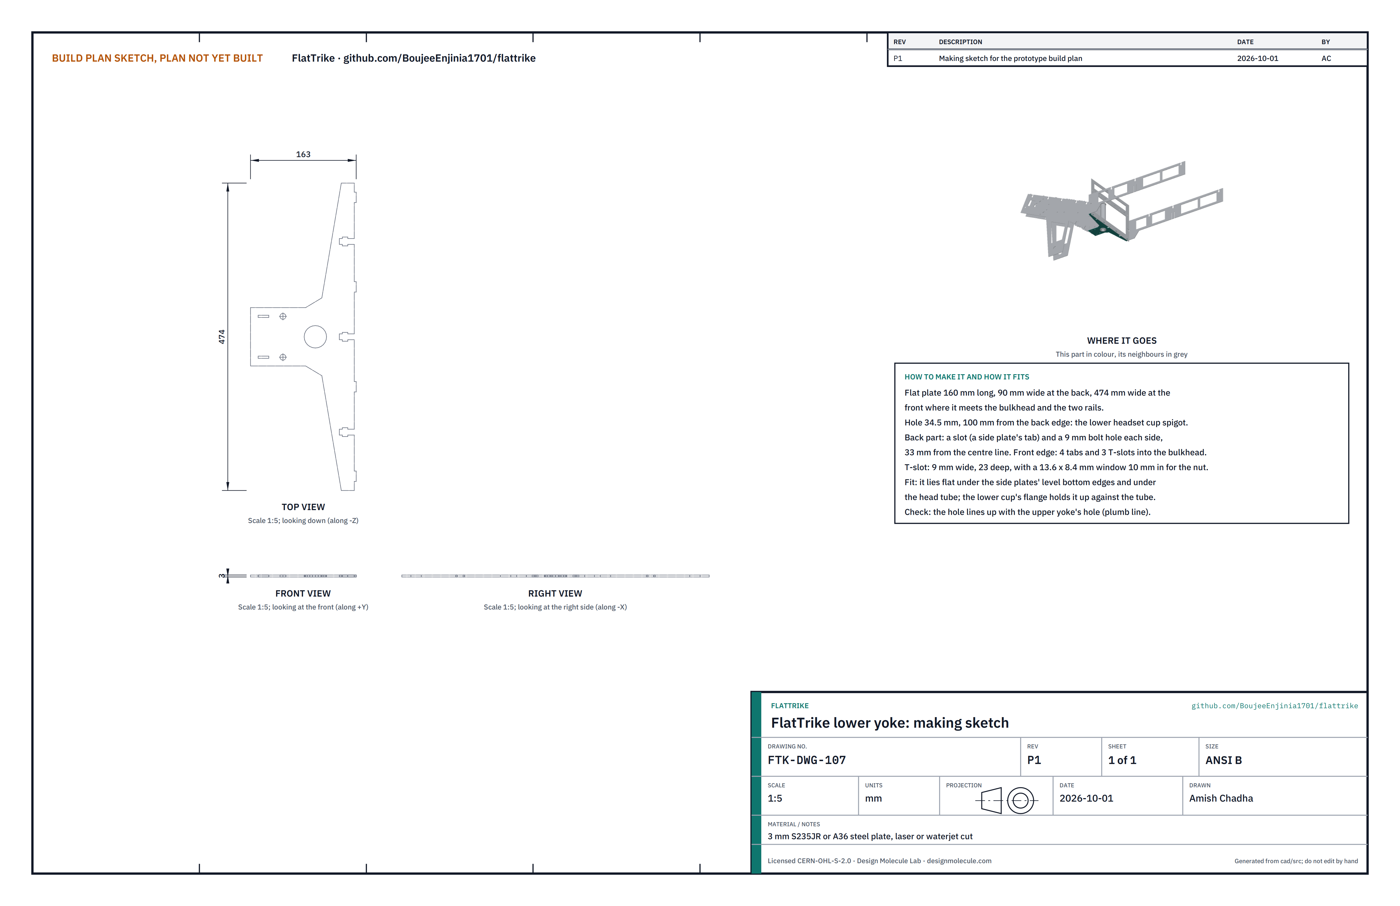
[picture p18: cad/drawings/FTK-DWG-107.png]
Figure 11. Making sketch of the lower yoke


*Figure 11. Lower yoke making sketch (FTK-DWG-107).*

**What it is and what it is made from.** The plate under the head tube that ties it to the spine, the bulkhead and the rails. 3 mm steel, 160 mm long, 90 mm wide at the back and 474 mm at the front, with a 34.5 mm hole 100 mm from the back edge.

**How to make it.** Deburr; check the hole as for the upper yoke.

**How it fits the parts next to it.** Its back end lies flat under the spine plates' level bottom edges, a slot and a bolt each side; the head tube's bottom end stands on it (Figure 13); its front edge's tabs go into the bulkhead.

**Check before moving on.** Held under the upper yoke, the two holes line up on a plumb line.

### 3.8 Head tubes and seat tube

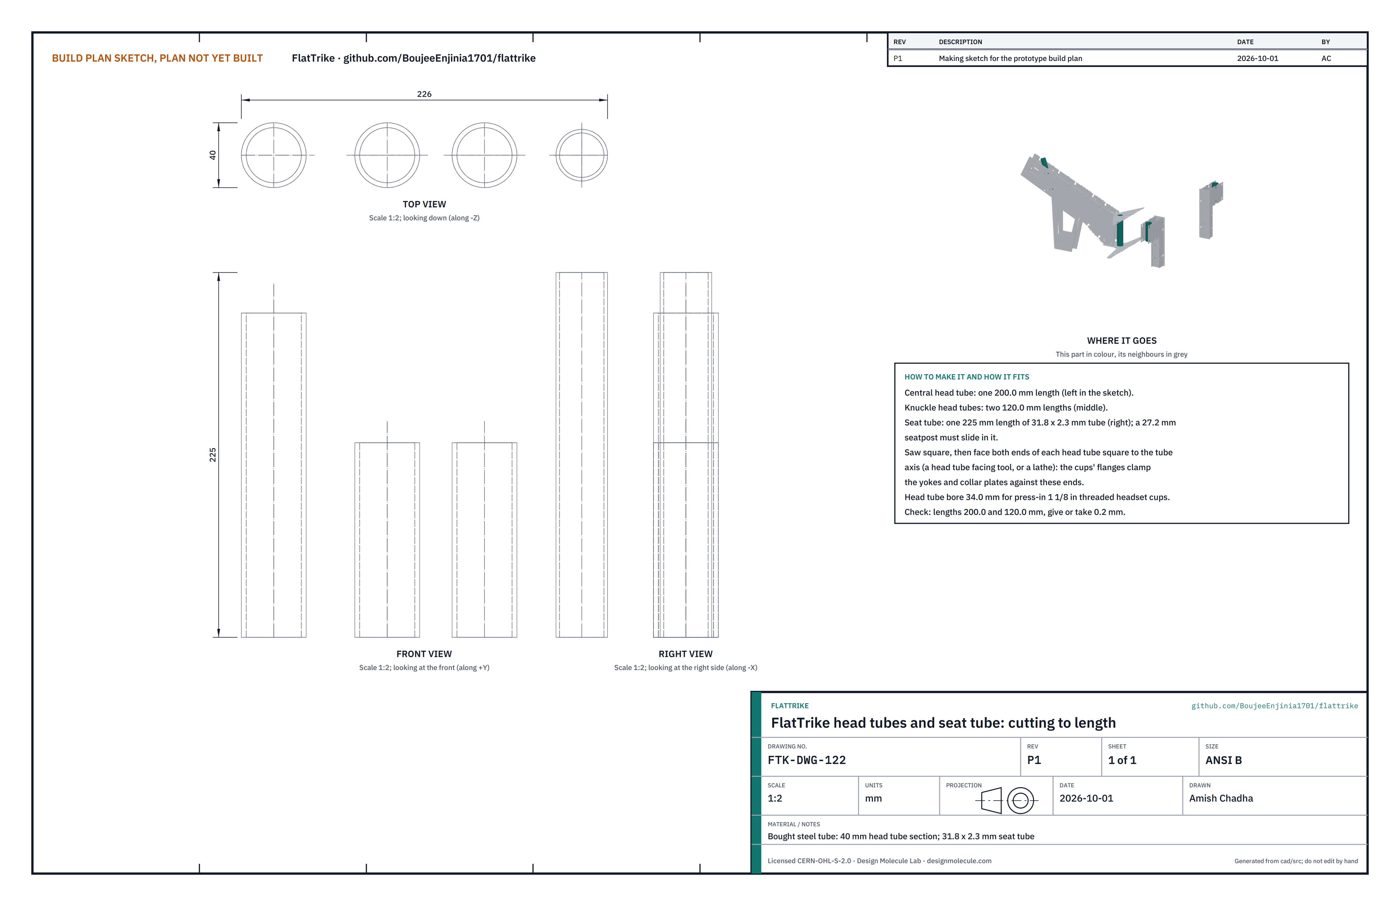
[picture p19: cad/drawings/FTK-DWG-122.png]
Figure 12. Cutting sketch of the head tubes and seat tube


*Figure 12. Head tubes and seat tube cutting sketch (FTK-DWG-122).*

**What it is and what it is made from.** Bought steel tube: a 40 mm head tube section with a 34.0 mm bore for 1 1/8 in threaded headset cups, and 31.8 x 2.3 mm tube for the seat tube.

**How to make it.**

1. Saw one 200.0 mm and two 120.0 mm lengths of head tube, and one 225 mm length of seat tube.
2. Face both ends of each head tube square to its axis with a head tube facing tool (a bicycle workshop has one) or a lathe.
3. Deburr inside and out. Check a 27.2 mm seatpost slides in the seat tube.

**How it fits the parts next to it.**

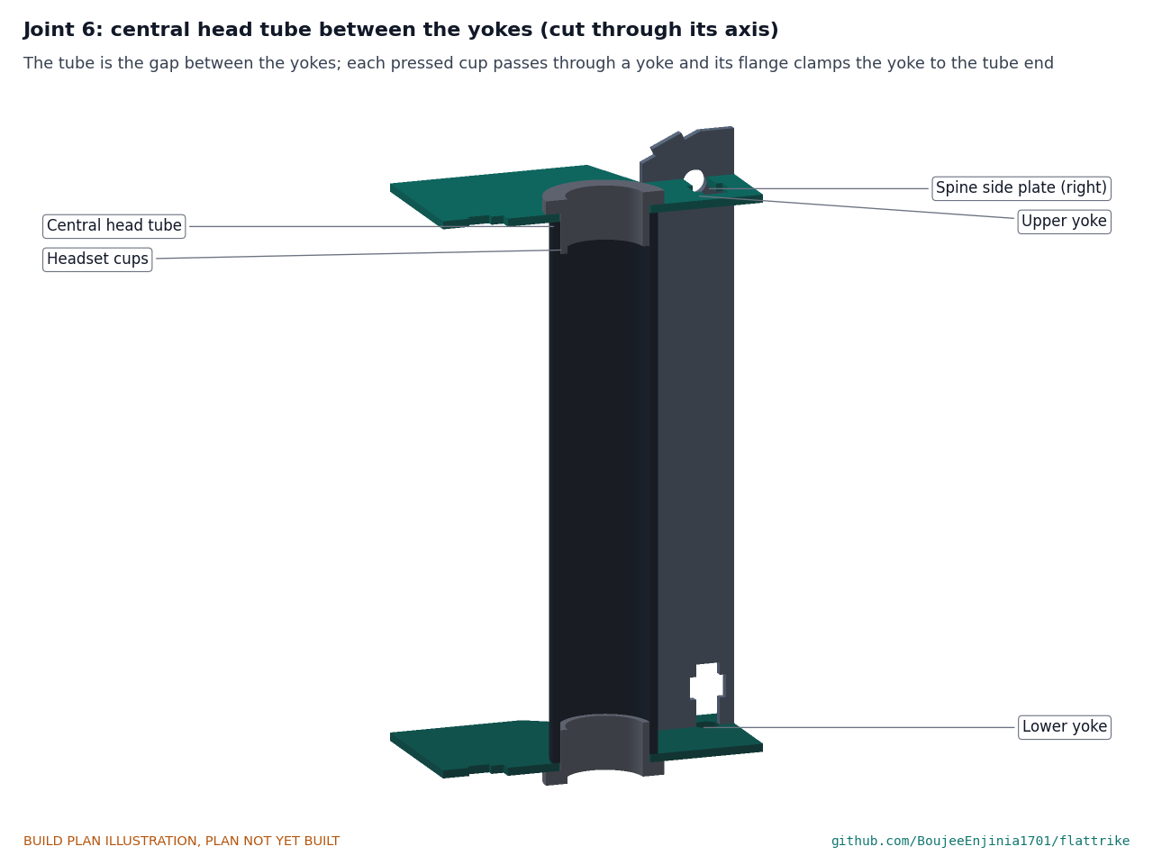
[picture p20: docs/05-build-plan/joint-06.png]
Figure 13. Joint 6: head tube between the yokes


*Figure 13. The head tube fills the gap between the yokes exactly; each pressed cup passes through a yoke and its flange clamps the yoke to the tube's end.*

The 120 mm knuckle head tubes sit the same way between their collar plates (Figure 30).

**Check before moving on.** Lengths 200.0 and 120.0 mm, give or take 0.2 mm; ends square.

### 3.9 Bottom bracket shell

**What it is and what it is made from.** A bought 68 mm steel bottom bracket shell section, cut to 60.0 mm and faced, and a square-taper cartridge bottom bracket for a 68 mm shell.

**How to make it.** Saw the shell to 60.0 mm, face both ends square, and chase the threads clean.

**How it fits the parts next to it.**

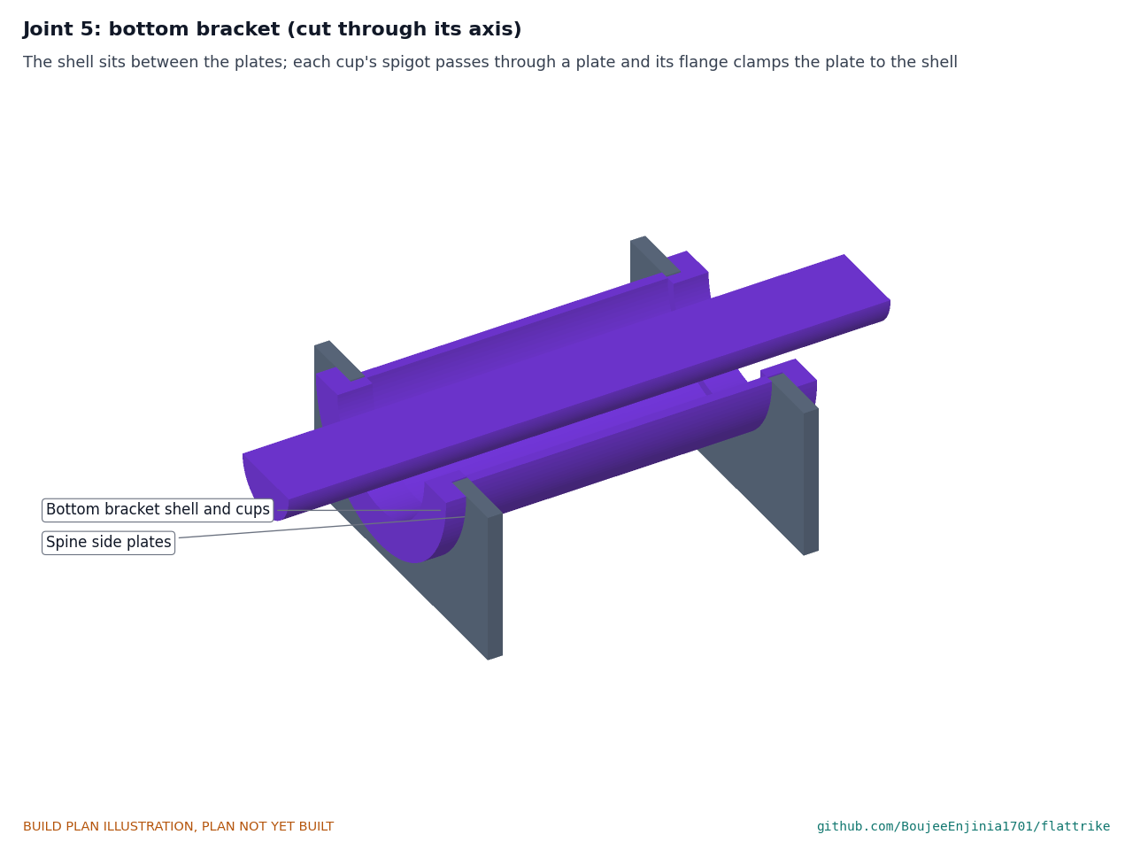
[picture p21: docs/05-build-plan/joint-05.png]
Figure 14. Joint 5: bottom bracket


*Figure 14. The shell sits between the spine plates; each cup screws in through a plate and its flange clamps the plate to the shell.*

**Check before moving on.** The shell is 60.0 mm long, give or take 0.2 mm.

### 3.10 Rear stay plates (make 2)

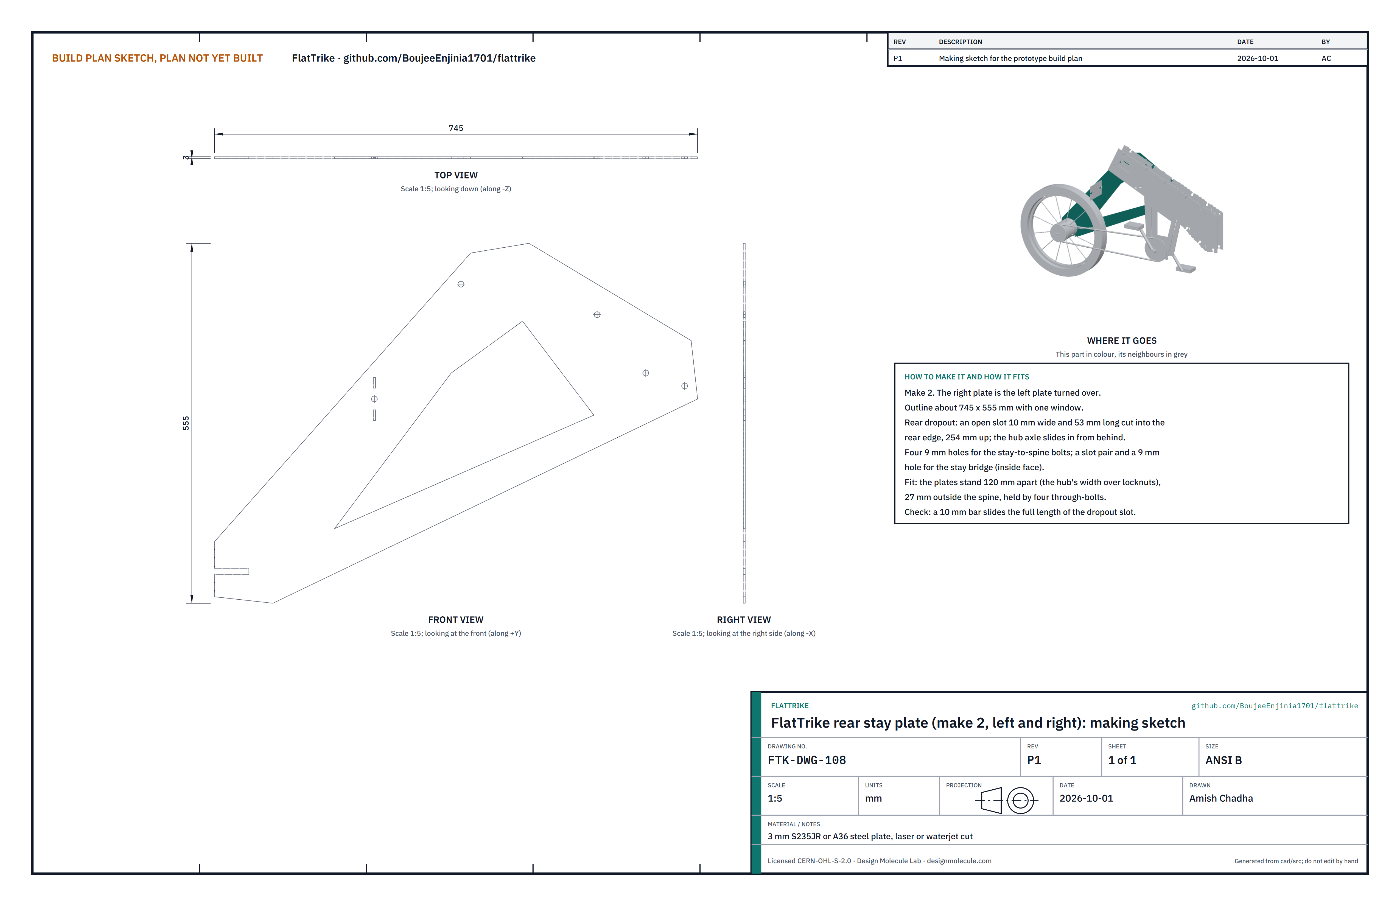
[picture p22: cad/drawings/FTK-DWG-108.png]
Figure 15. Making sketch of the rear stay plate


*Figure 15. Rear stay plate making sketch (FTK-DWG-108).*

**What it is and what it is made from.** The two plates that carry the rear wheel and join it to the spine. 3 mm steel, about 745 x 555 mm, with an open dropout slot in the rear edge.

**How to make it.** Deburr, especially the dropout slot: the hub axle and its washers bear on it. The right plate is the left turned over.

**How it fits the parts next to it.** The plates stand 120 mm apart, the hub's width, 27 mm outside the spine, held by four through-bolts (Figure 19) and braced by the stay bridge.

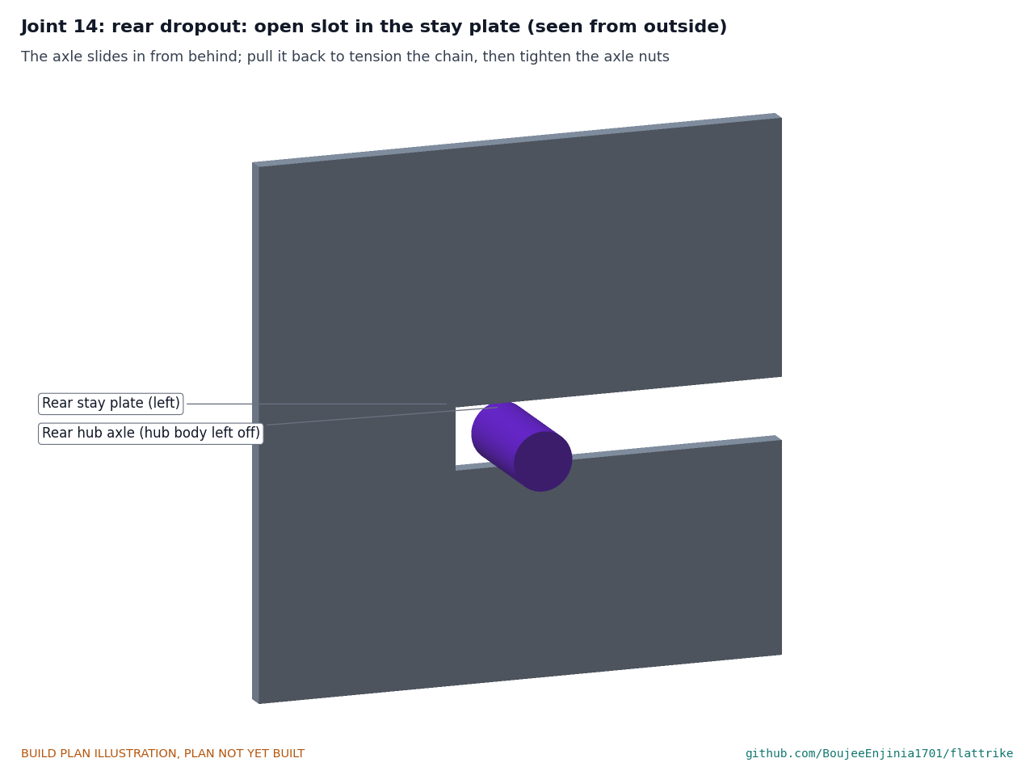
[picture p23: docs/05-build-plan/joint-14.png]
Figure 16. Joint 14: rear dropout


*Figure 16. The axle slides into the slot from behind; pull the wheel back to tension the chain, then tighten the axle nuts.*

**Check before moving on.** A 10 mm bar slides the full length of each dropout slot.

### 3.11 Stay bridge

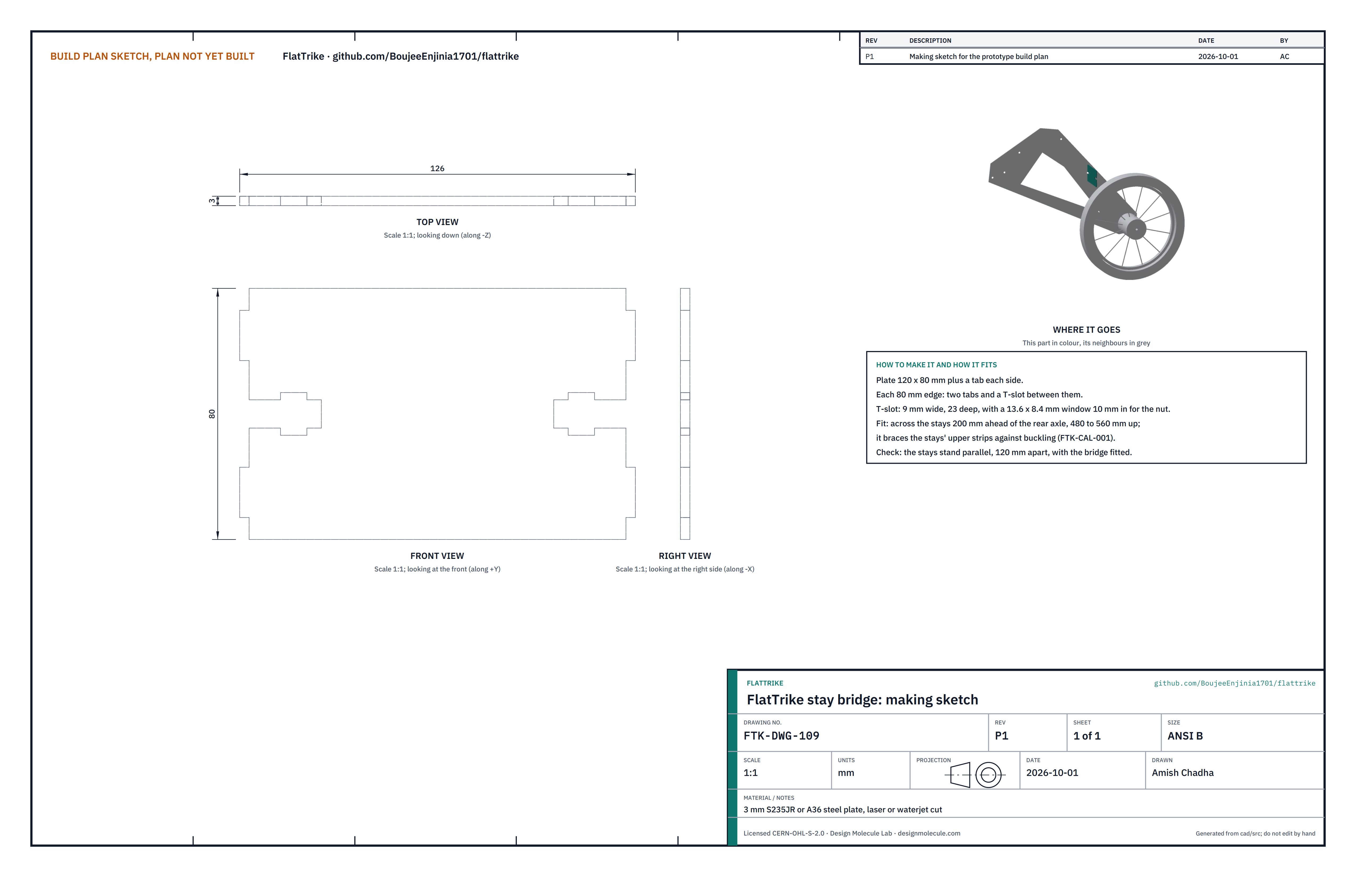
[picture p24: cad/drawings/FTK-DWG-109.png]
Figure 17. Making sketch of the stay bridge


*Figure 17. Stay bridge making sketch (FTK-DWG-109).*

**What it is and what it is made from.** A cross plate between the stays that stops their upper strips buckling. 3 mm steel, 120 x 80 mm plus a tab each side.

**How to make it.** Deburr.

**How it fits the parts next to it.** Two tabs and one bolt each side into the stays, 200 mm ahead of the rear axle and 480 to 560 mm up (step 8).

**Check before moving on.** Fitted between the stays, the stays stand parallel.

### 3.12 Spacer washers and spacer tubes

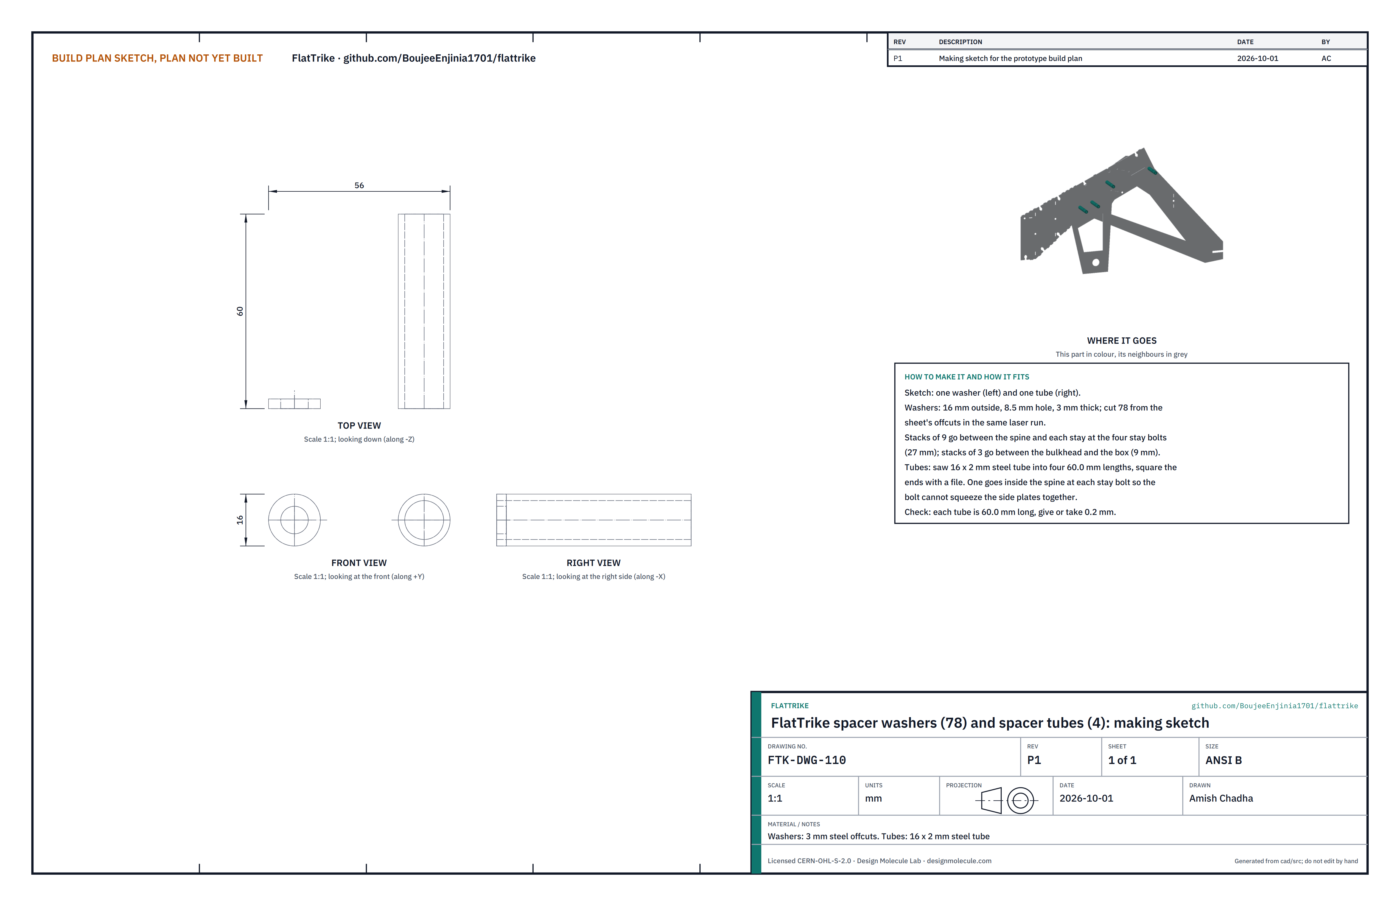
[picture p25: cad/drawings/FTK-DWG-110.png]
Figure 18. Making sketch of the spacer washers and tubes


*Figure 18. Spacer washer and spacer tube making sketch (FTK-DWG-110).*

**What it is and what it is made from.** 78 washers, 16 mm outside, 8.5 mm hole, cut from the sheet's offcuts; four 60.0 mm lengths of 16 x 2 mm steel tube.

**How to make it.** Deburr the washers in a tumbler or by hand; saw and file the tubes square to length.

**How it fits the parts next to it.**

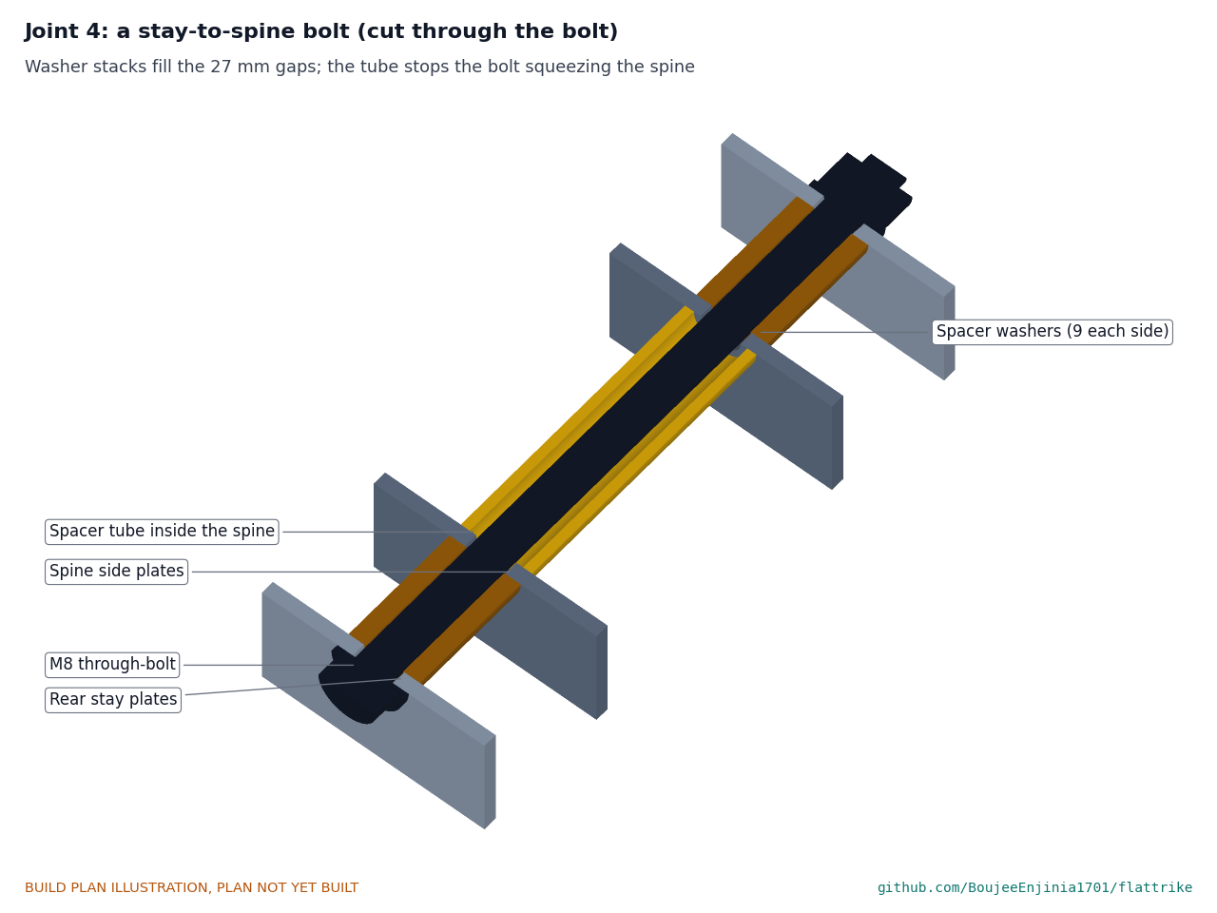
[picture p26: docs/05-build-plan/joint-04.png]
Figure 19. Joint 4: a stay-to-spine bolt


*Figure 19. Nine washers fill each 27 mm gap between spine and stay; the tube inside the spine stops the bolt squeezing it.*

Stacks of three go behind the box (Figure 39).

**Check before moving on.** Each tube is 60.0 mm long, give or take 0.2 mm.

### 3.13 Bulkhead

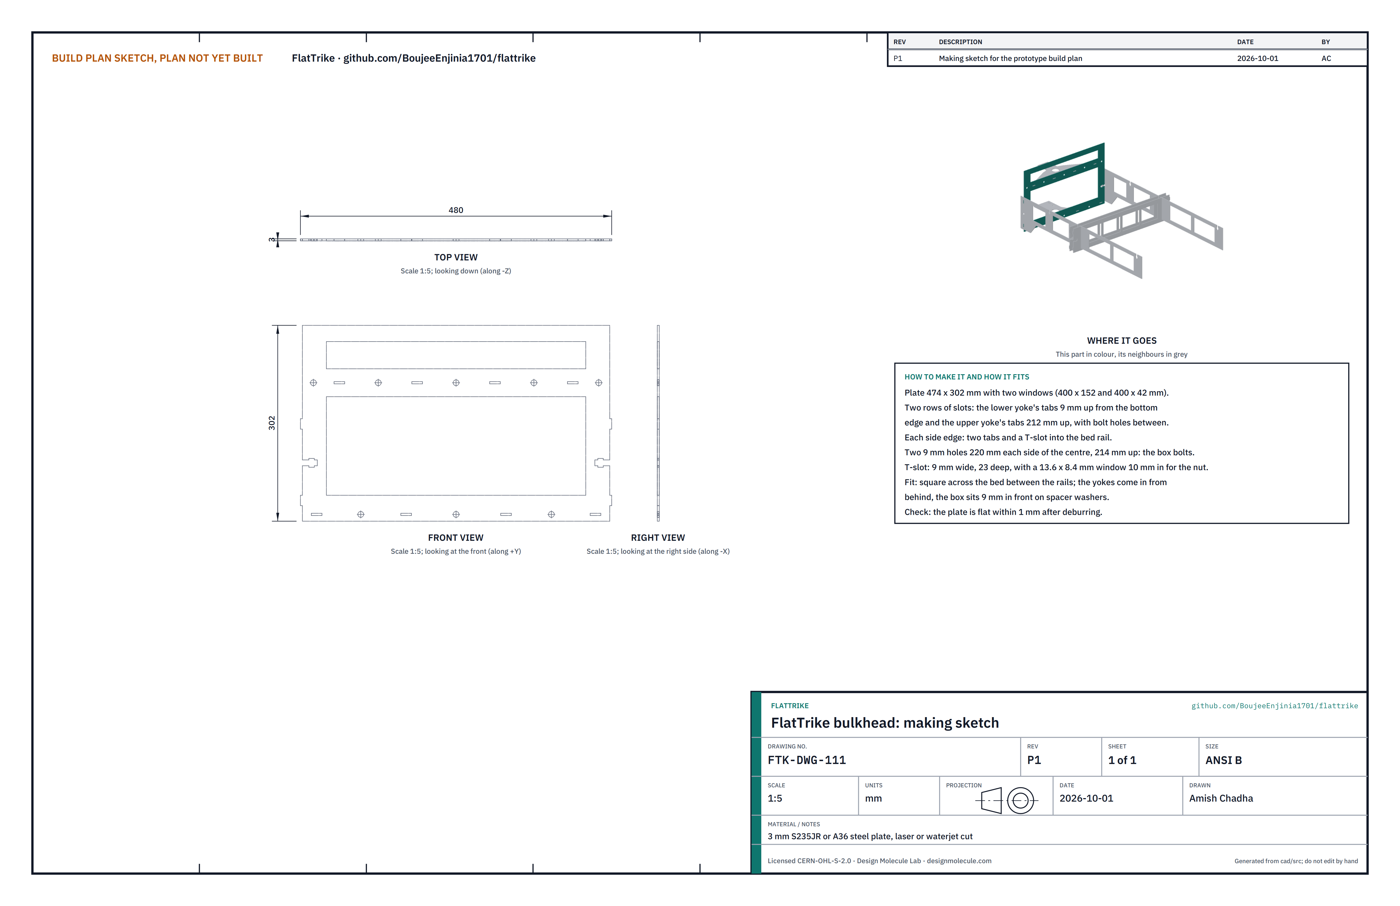
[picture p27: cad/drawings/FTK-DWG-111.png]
Figure 20. Making sketch of the bulkhead


*Figure 20. Bulkhead making sketch (FTK-DWG-111).*

**What it is and what it is made from.** The cross plate at the front of the spine that the yokes, rails and box join. 3 mm steel, 474 x 302 mm, with two windows.

**How to make it.** Deburr; check it is flat within 1 mm.

**How it fits the parts next to it.**

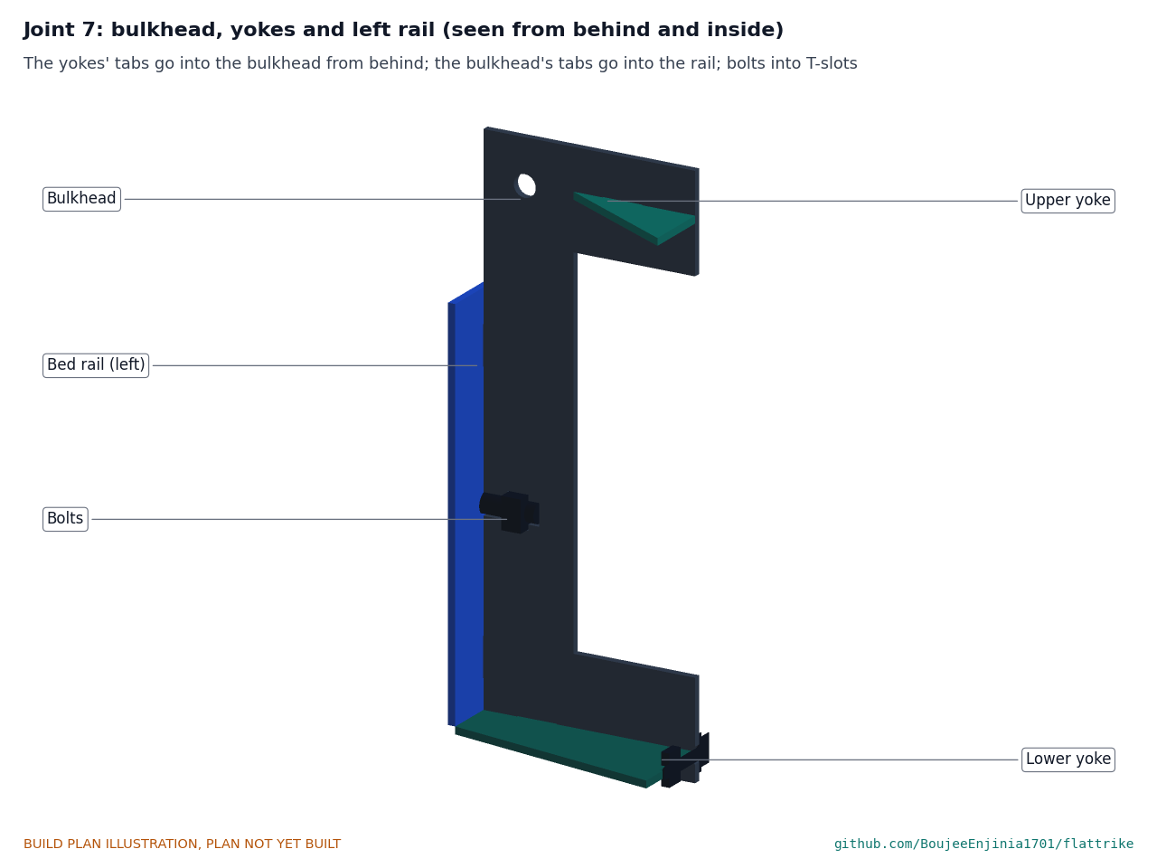
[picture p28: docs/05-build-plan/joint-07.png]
Figure 21. Joint 7: bulkhead, yokes and rail


*Figure 21. The yokes' tabs go into the bulkhead from behind, the bulkhead's side tabs go into the rails, and bolts close each joint.*

**Check before moving on.** Offered up to both yokes, every yoke tab enters its slot.

### 3.14 Bed rails (make 2)

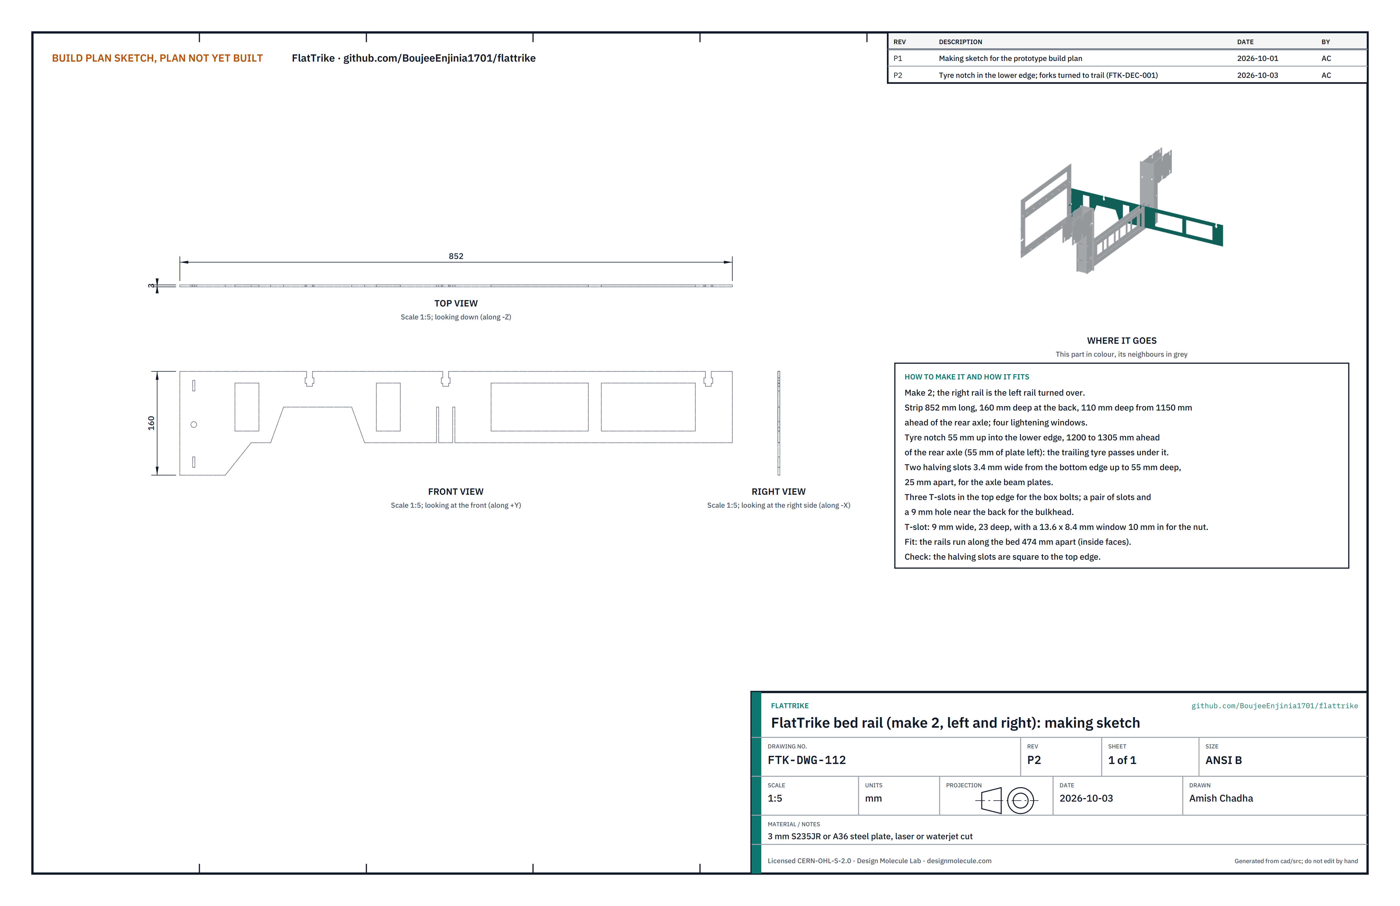
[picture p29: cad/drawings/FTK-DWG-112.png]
Figure 22. Making sketch of the bed rail


*Figure 22. Bed rail making sketch (FTK-DWG-112).*

**What it is and what it is made from.** The two side members of the bed, under the box. 3 mm steel, 852 mm long, 160 mm deep at the back and 110 mm deep from 1,150 mm ahead of the rear axle, with four windows. A notch 55 mm up into the lower edge, 1,200 to 1,305 mm ahead of the rear axle, lets the trailing inner tyre pass under the rail at full lock.

**How to make it.** Deburr; the right rail is the left turned over.

**How it fits the parts next to it.**

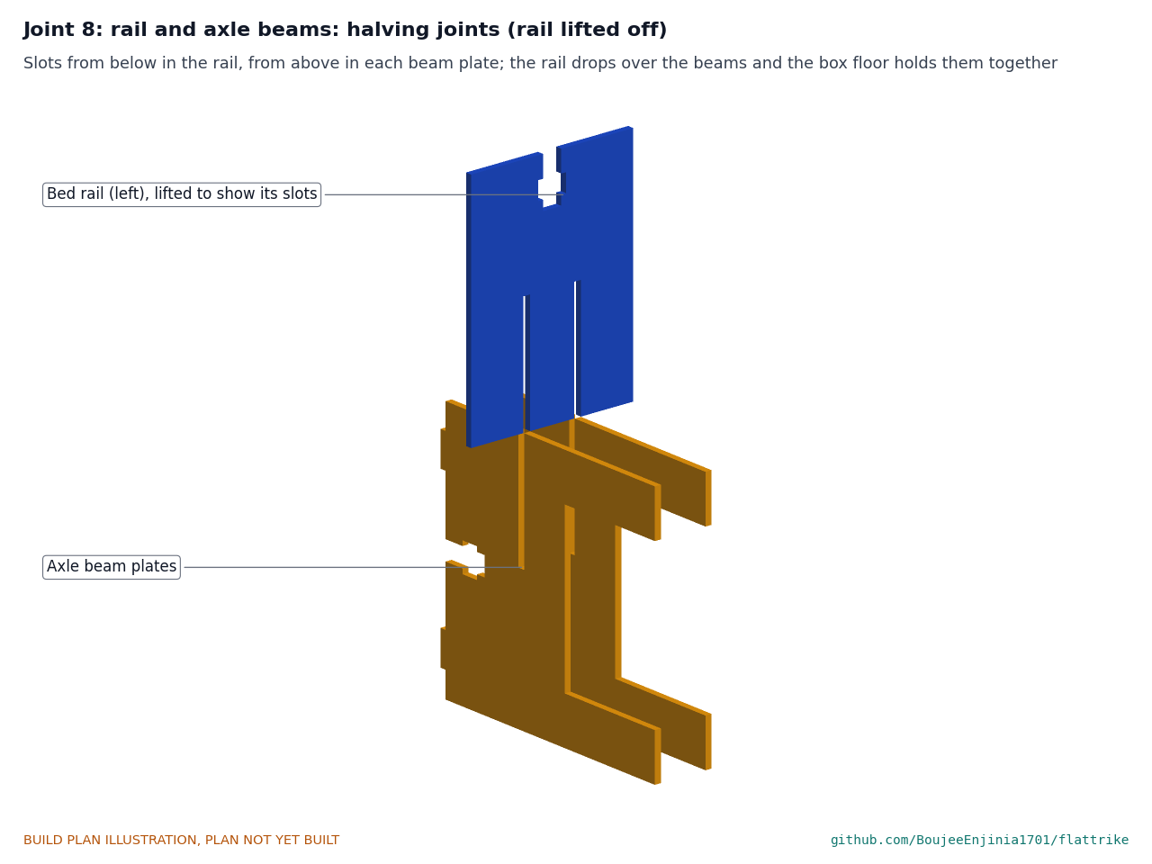
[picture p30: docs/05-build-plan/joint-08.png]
Figure 23. Joint 8: rail and axle beams


*Figure 23. Halving joints: a slot up from the rail's bottom edge and a slot down from each beam plate's top edge; the box floor holds them closed.*

**Check before moving on.** The halving slots are square to the top edge.

### 3.15 Axle beam plates (make 2)

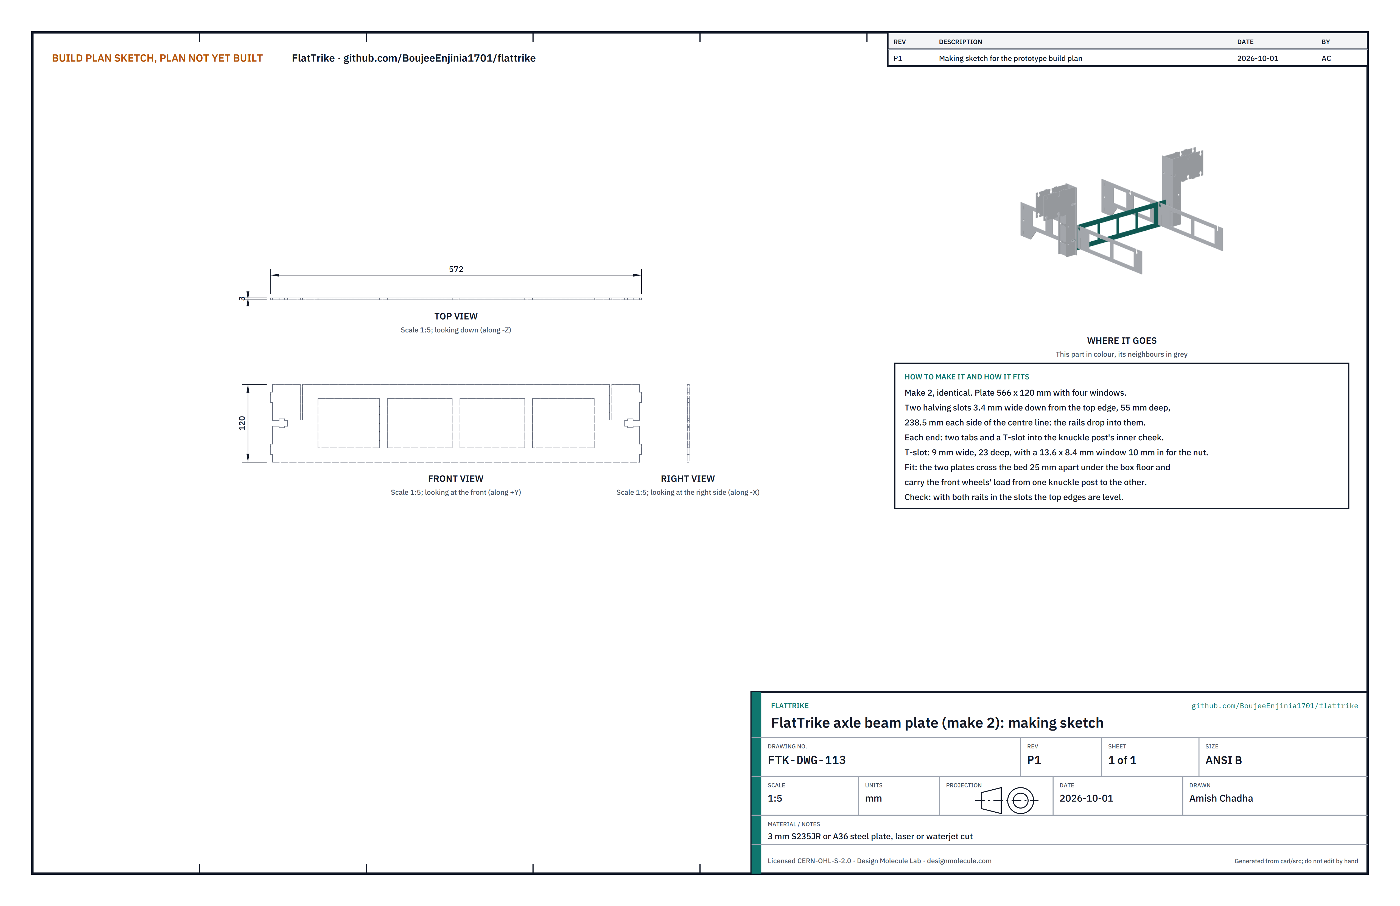
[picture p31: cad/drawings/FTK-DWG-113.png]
Figure 24. Making sketch of the axle beam plate


*Figure 24. Axle beam plate making sketch (FTK-DWG-113).*

**What it is and what it is made from.** Twin plates that cross the bed under the box and carry the front wheels' load from one knuckle post to the other. 3 mm steel, 566 x 120 mm, with four windows.

**How to make it.** Deburr. The two plates are the same.

**How it fits the parts next to it.** They cross the bed 25 mm apart, halved into the rails (Figure 23), with two tabs and a bolt at each end into a knuckle post's inner cheek (Figure 26).

**Check before moving on.** With both rails in the slots, the top edges are level.

### 3.16 Knuckle post plates (make 4)

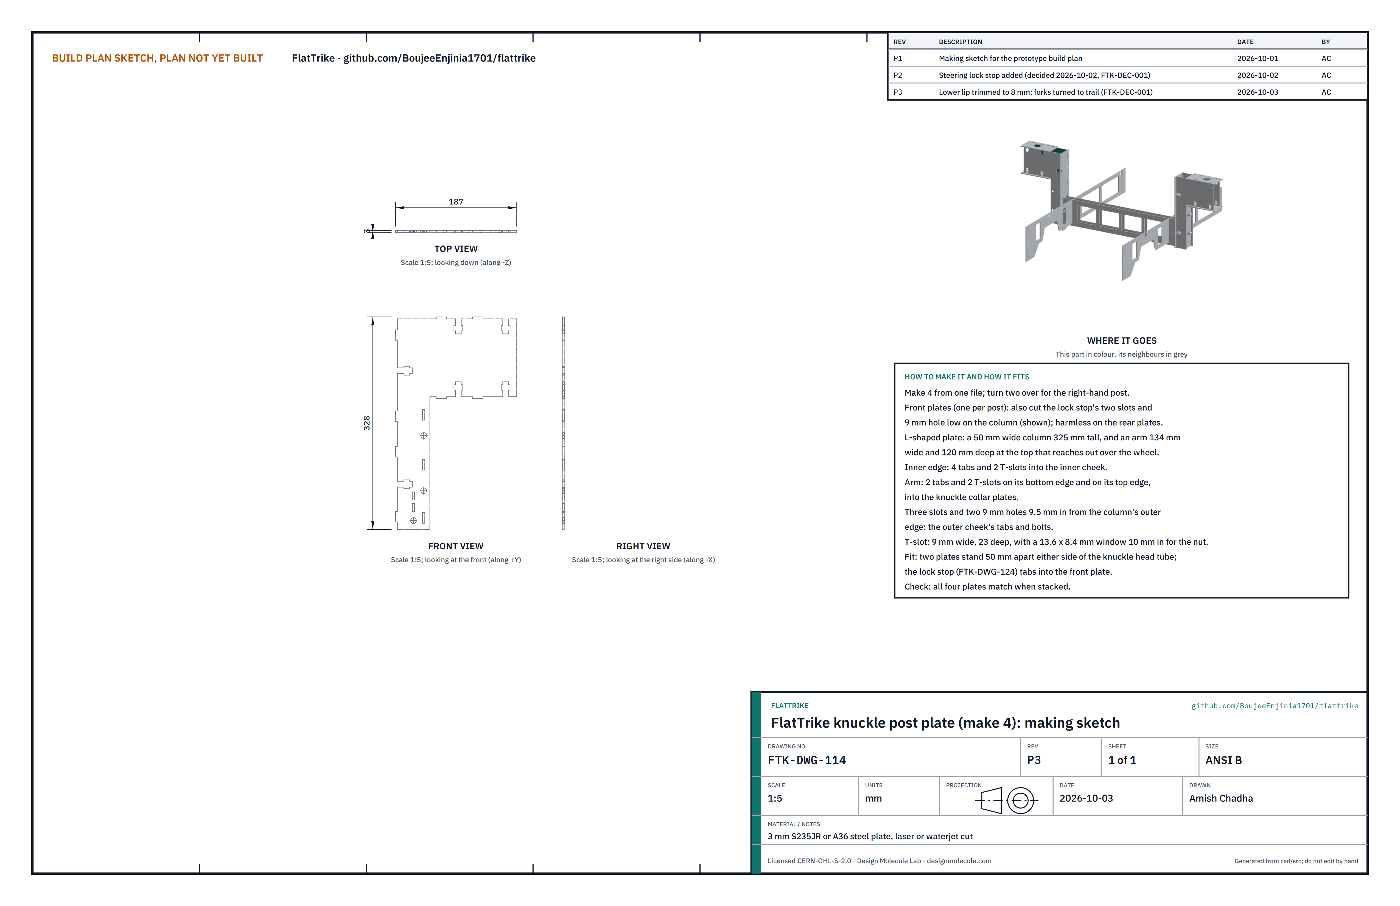
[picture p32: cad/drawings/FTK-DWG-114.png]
Figure 25. Making sketch of the knuckle post plate


*Figure 25. Knuckle post plate making sketch (FTK-DWG-114).*

**What it is and what it is made from.** Each knuckle post, which holds a front wheel's fork, is a box of two L-shaped plates and two cheeks, with a collar plate under and over the knuckle head tube. 3 mm steel; the post plate is a column 50 mm wide and 325 mm tall with an arm 134 mm wide and 120 mm deep at the top.

**How to make it.** Deburr. All four are the same; turn two over for the right-hand post. The two slots and the hole low on the column take the lock stop (section 3.24); they are cut in all four plates but used only on the front one of each post.

**How it fits the parts next to it.**

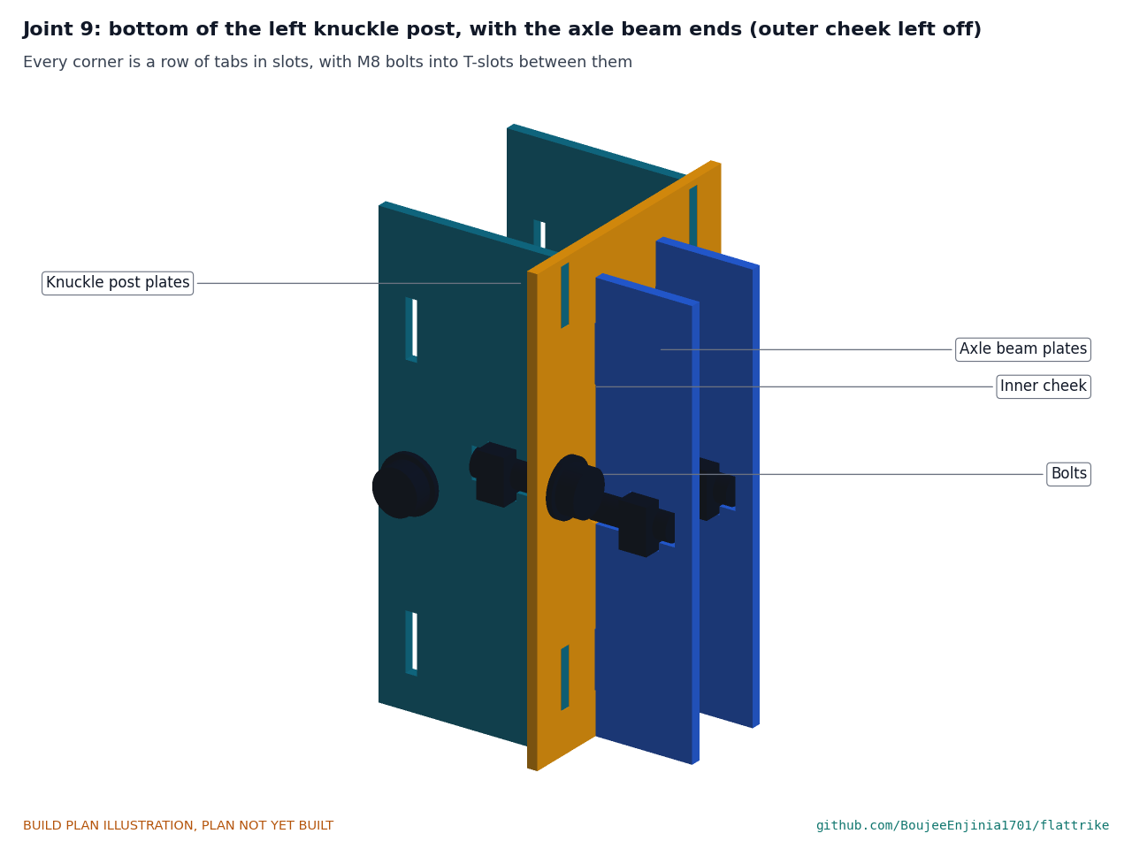
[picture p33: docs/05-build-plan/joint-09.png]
Figure 26. Joint 9: bottom of the left knuckle post


*Figure 26. The post plates' tabs go into the inner cheek; the outer cheek's tabs go into the post plates; the axle beams' end tabs go into the inner cheek. Bolts into T-slots close each joint.*

**Check before moving on.** All four plates match when stacked.

### 3.17 Knuckle post inner cheeks (make 2)

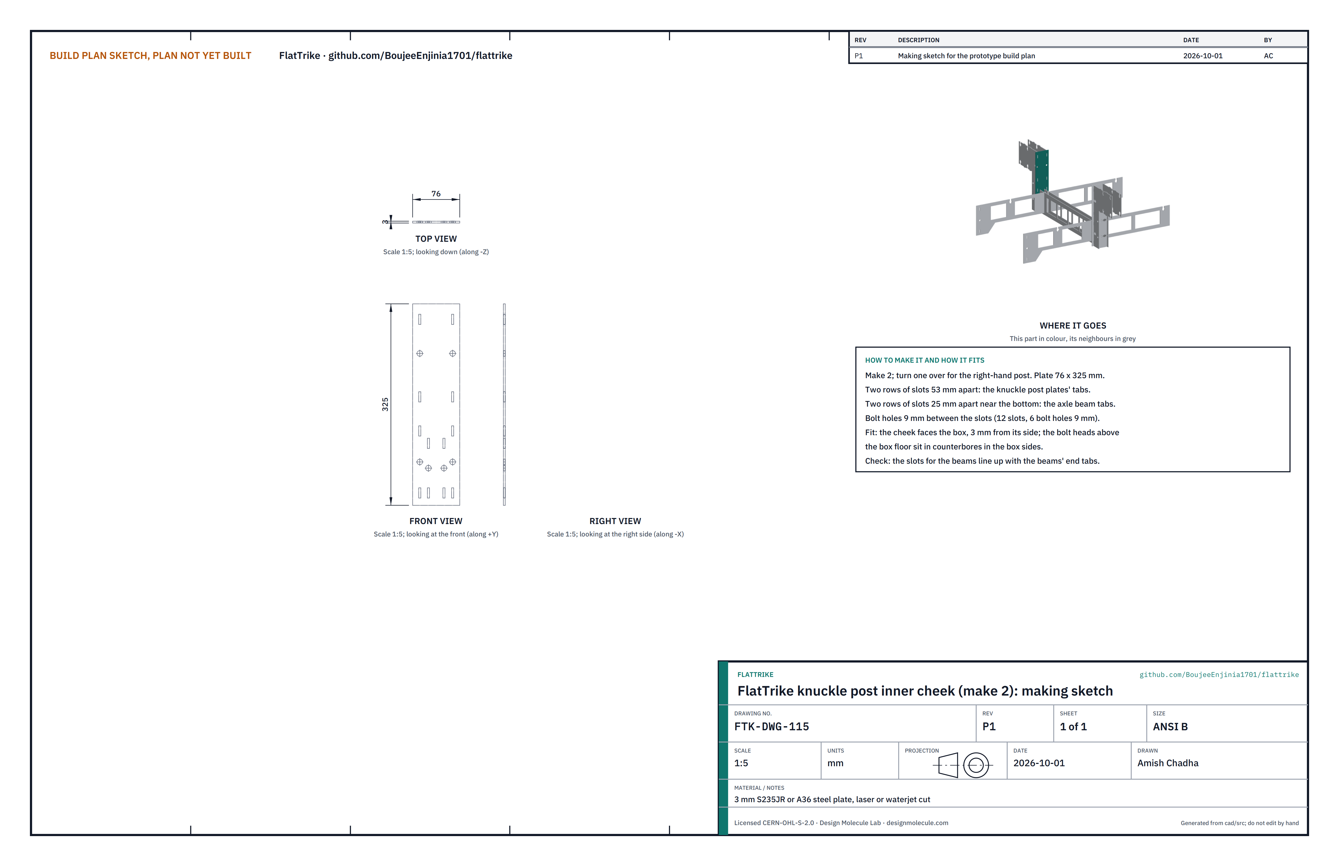
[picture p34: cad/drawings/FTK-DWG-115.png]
Figure 27. Making sketch of the inner cheek


*Figure 27. Inner cheek making sketch (FTK-DWG-115).*

**What it is and what it is made from.** The post's inboard wall, facing the box. 3 mm steel, 76 x 325 mm.

**How to make it.** Deburr; turn one over for the right-hand post.

**How it fits the parts next to it.** The post plates and the axle beams tab into it (Figure 26). It stands 3 mm from the box side; the two bolt heads above the box floor sit in counterbores in the box sides (section 3.25).

**Check before moving on.** The beam slots line up with the beams' end tabs.

### 3.18 Knuckle post outer cheeks (make 2)

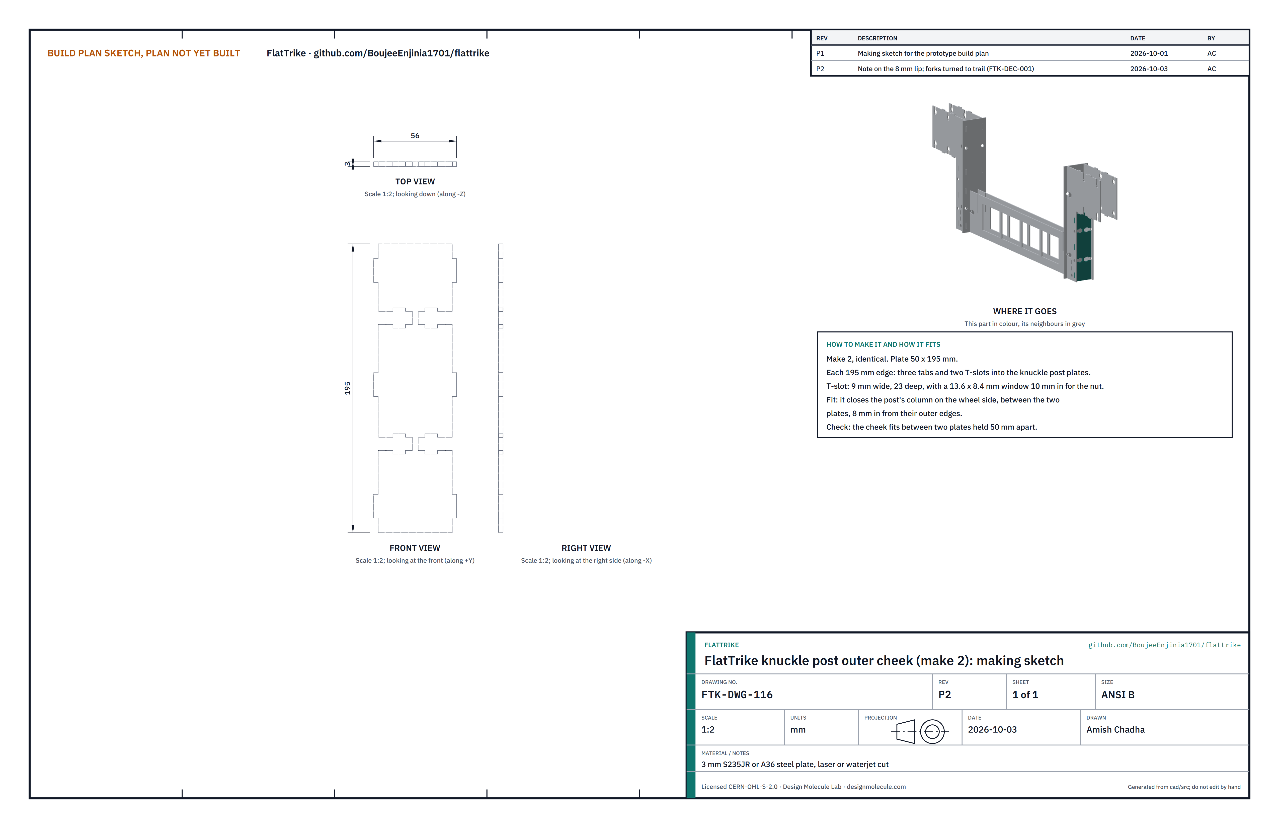
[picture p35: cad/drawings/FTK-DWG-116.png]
Figure 28. Making sketch of the outer cheek


*Figure 28. Outer cheek making sketch (FTK-DWG-116).*

**What it is and what it is made from.** The post's wall on the wheel side. 3 mm steel, 50 x 195 mm.

**How to make it.** Deburr.

**How it fits the parts next to it.** It sits between the two post plates, 10 mm in from their outer edges, with three tabs and two bolts each side (Figure 26).

**Check before moving on.** It fits between two plates held 50 mm apart.

### 3.19 Knuckle collar plates (make 4)

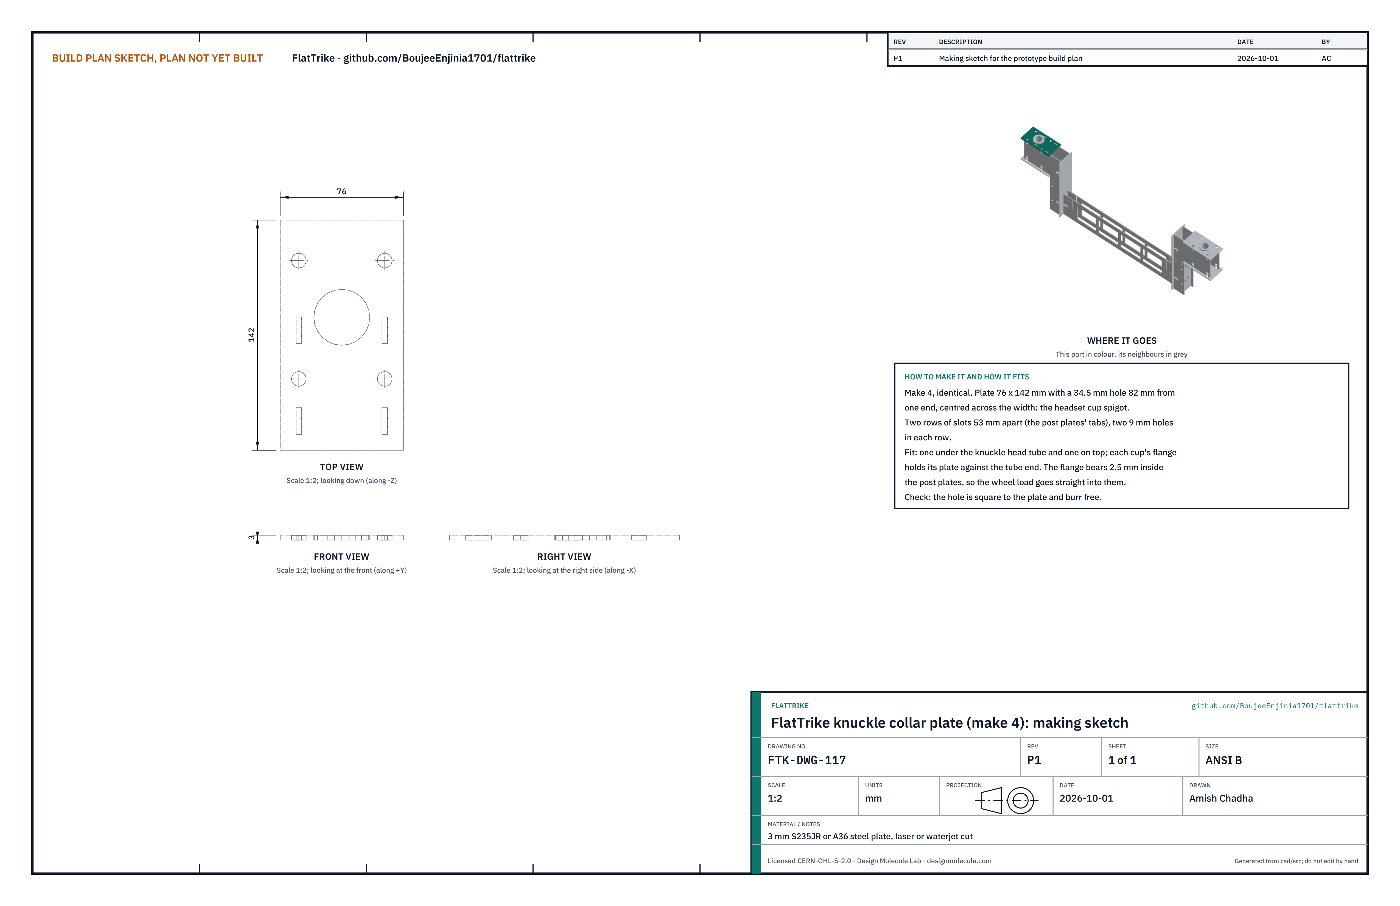
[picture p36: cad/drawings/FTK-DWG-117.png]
Figure 29. Making sketch of the knuckle collar plate


*Figure 29. Knuckle collar plate making sketch (FTK-DWG-117).*

**What it is and what it is made from.** The plates under and over each knuckle head tube. 3 mm steel, 76 x 142 mm, with a 34.5 mm hole 82 mm from one end.

**How to make it.** Deburr the hole carefully.

**How it fits the parts next to it.**

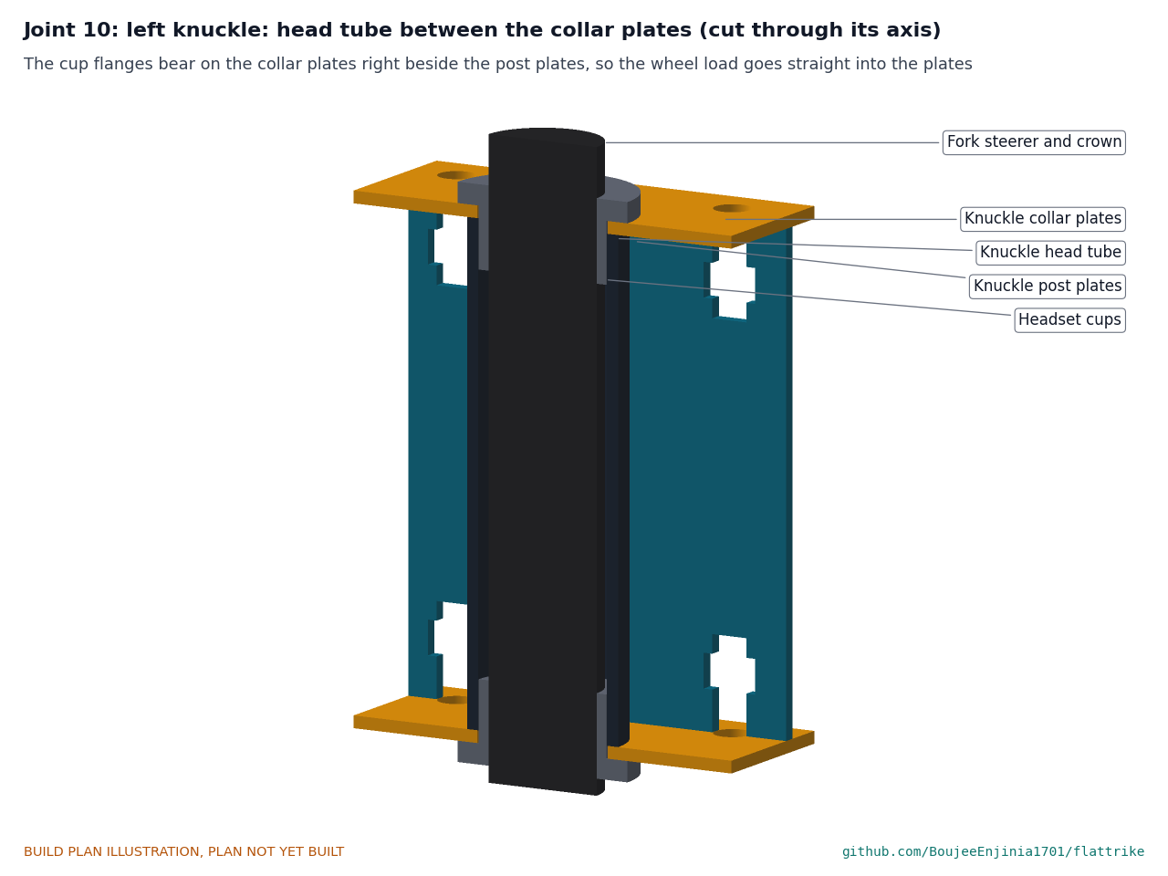
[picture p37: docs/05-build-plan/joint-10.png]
Figure 30. Joint 10: knuckle head tube between its collar plates


*Figure 30. Each cup's flange bears on its collar plate right beside the post plates, so a wheel's load goes straight into the plates.*

The post plates' arms tab into the collar plates, two tabs and two bolts each.

**Check before moving on.** The hole is square to the plate and burr free.

### 3.20 Steering column

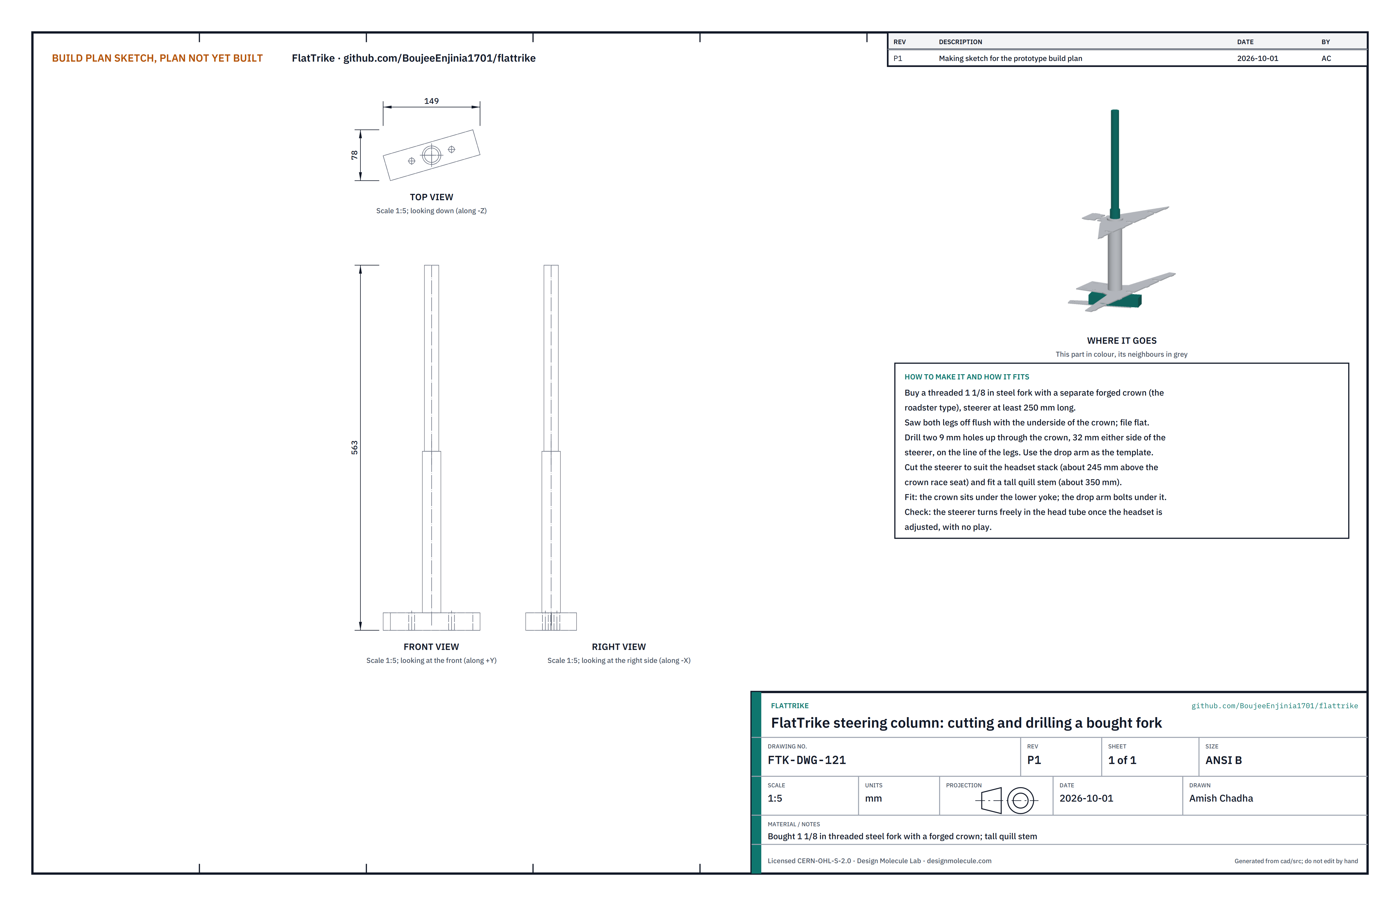
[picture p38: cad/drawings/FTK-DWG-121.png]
Figure 31. Cutting and drilling sketch of the steering column fork


*Figure 31. Steering column cutting and drilling sketch (FTK-DWG-121).*

**What it is and what it is made from.** A bought 1 1/8 in threaded steel fork with a separate forged crown (the roadster type), with a steerer at least 250 mm long, and a tall quill stem.

**How to make it.**

1. Saw both legs off flush with the underside of the crown and file it flat.
2. Clamp the drop arm under the crown as a template, on the line of the legs, and drill two 9 mm holes up through the crown, 32 mm either side of the steerer.
3. Cut the steerer to suit the headset stack, about 245 mm above the crown race seat.

**How it fits the parts next to it.** The steerer runs up through the central head tube on its headset; the crown sits under the lower yoke; the drop arm bolts under the crown (Figure 33).

**Check before moving on.** The drop arm's holes line up with the crown's.

### 3.21 Drop arm

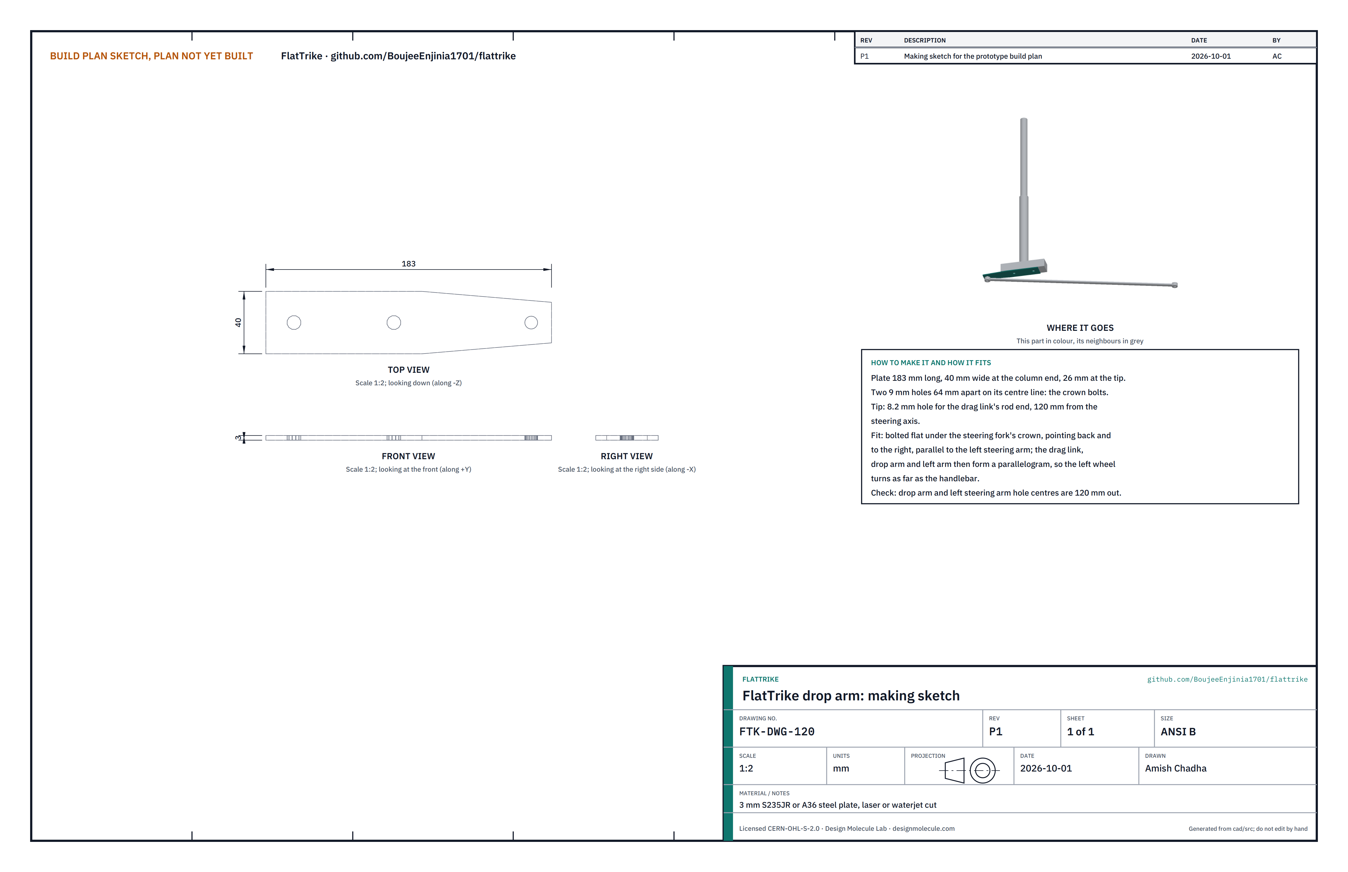
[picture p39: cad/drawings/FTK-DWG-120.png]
Figure 32. Making sketch of the drop arm


*Figure 32. Drop arm making sketch (FTK-DWG-120).*

**What it is and what it is made from.** The arm under the steering column that drives the left wheel through the drag link. 3 mm steel, 183 mm long.

**How to make it.** Deburr.

**How it fits the parts next to it.**

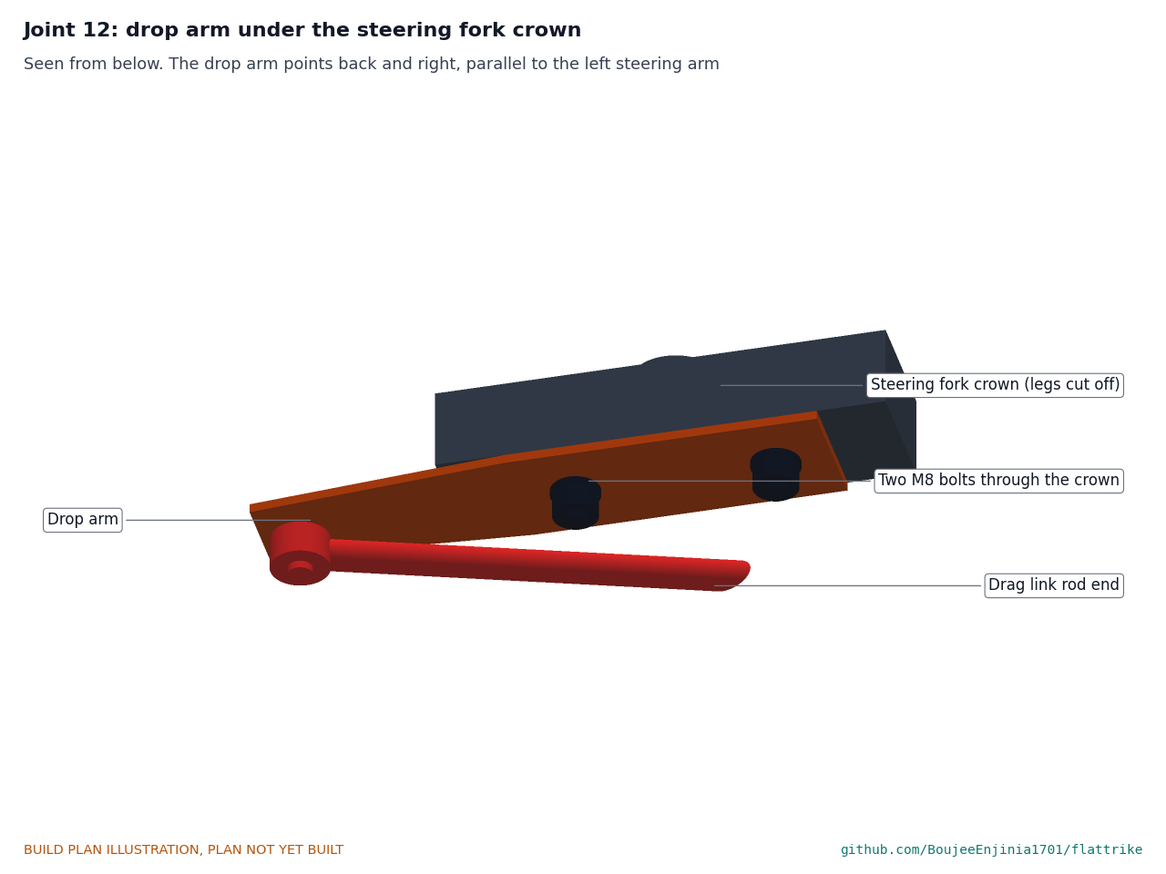
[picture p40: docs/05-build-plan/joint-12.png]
Figure 33. Joint 12: drop arm under the crown


*Figure 33. Two M8 bolts through the crown hold the drop arm; the drag link's rod end bolts under its tip.*

The drop arm points back and to the right, parallel to the left steering arm and 120 mm long like it, so the column, drop arm, drag link and left arm form a parallelogram.

**Check before moving on.** Its tip hole is 120 mm from the steering axis, give or take 1 mm.

### 3.22 Steering arms (make 2)

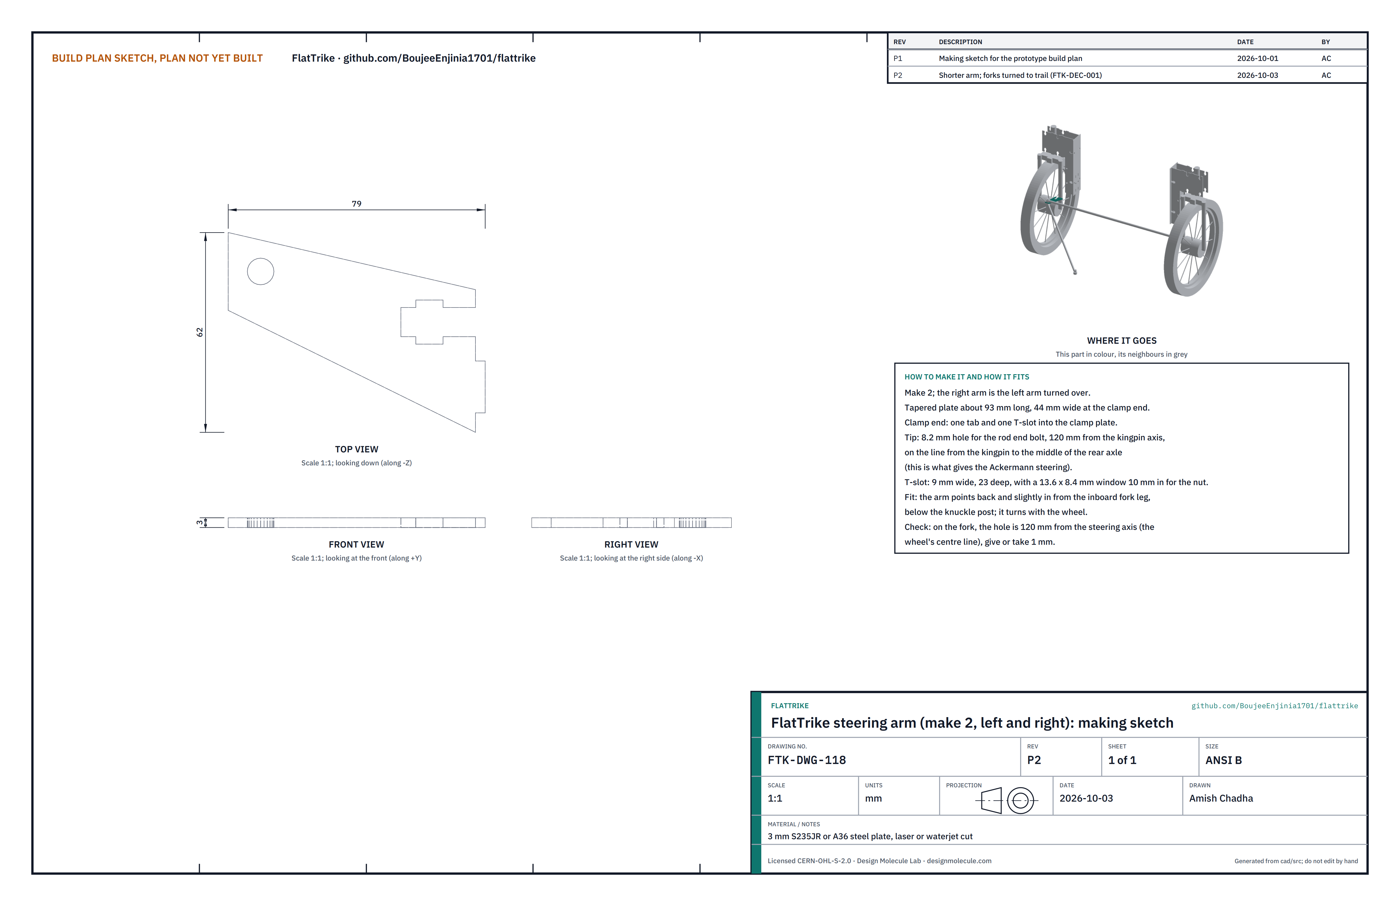
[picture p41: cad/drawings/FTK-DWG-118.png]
Figure 34. Making sketch of the steering arm


*Figure 34. Steering arm making sketch (FTK-DWG-118).*

**What it is and what it is made from.** One arm on each front fork, joined by the tie rod. 3 mm steel, about 93 mm long, 44 mm wide at the clamp end (shorter than before, because the fork leg it clamps to now trails the steering axis by 35 mm).

**How to make it.** Deburr; the right arm is the left turned over.

**How it fits the parts next to it.** Its tip hole is 120 mm from the wheel's steering axis, on the line from the steering axis to the middle of the rear axle; this is what makes the inner wheel turn more than the outer one. It tabs and bolts into the clamp plate (Figure 36).

**Check before moving on.** On the fork, the tip hole is 120 mm from the steering axis, give or take 1 mm.

### 3.23 Steering arm clamp plates (make 2)

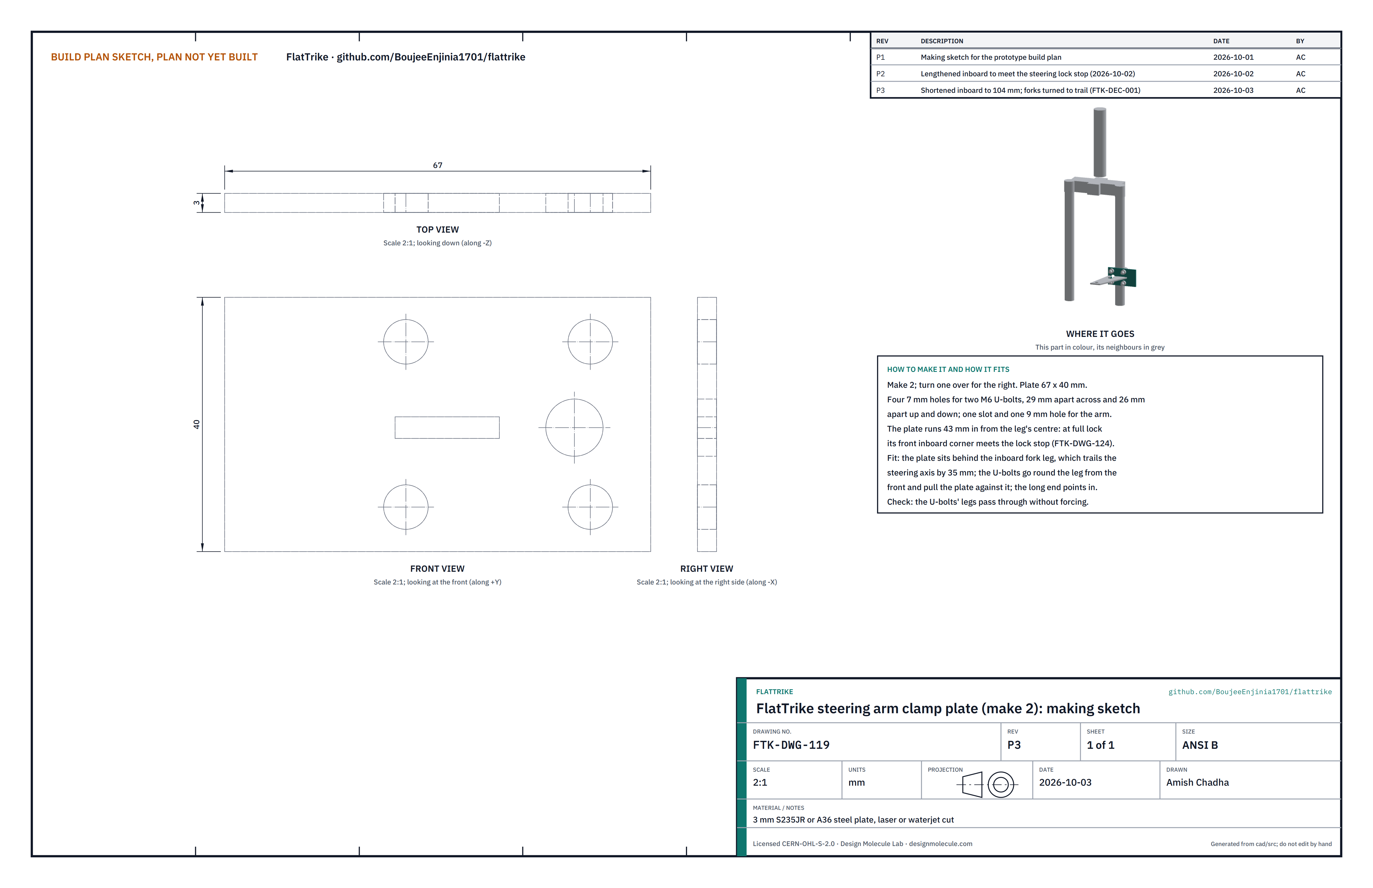
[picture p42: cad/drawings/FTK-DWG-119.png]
Figure 35. Making sketch of the clamp plate


*Figure 35. Steering arm clamp plate making sketch (FTK-DWG-119).*

**What it is and what it is made from.** A small plate that clamps each steering arm to its fork leg. 3 mm steel, 67 x 40 mm. Its long end reaches inboard so that, at full lock, its front inner corner meets the lock stop (section 3.24).

**How to make it.** Deburr.

**How it fits the parts next to it.**

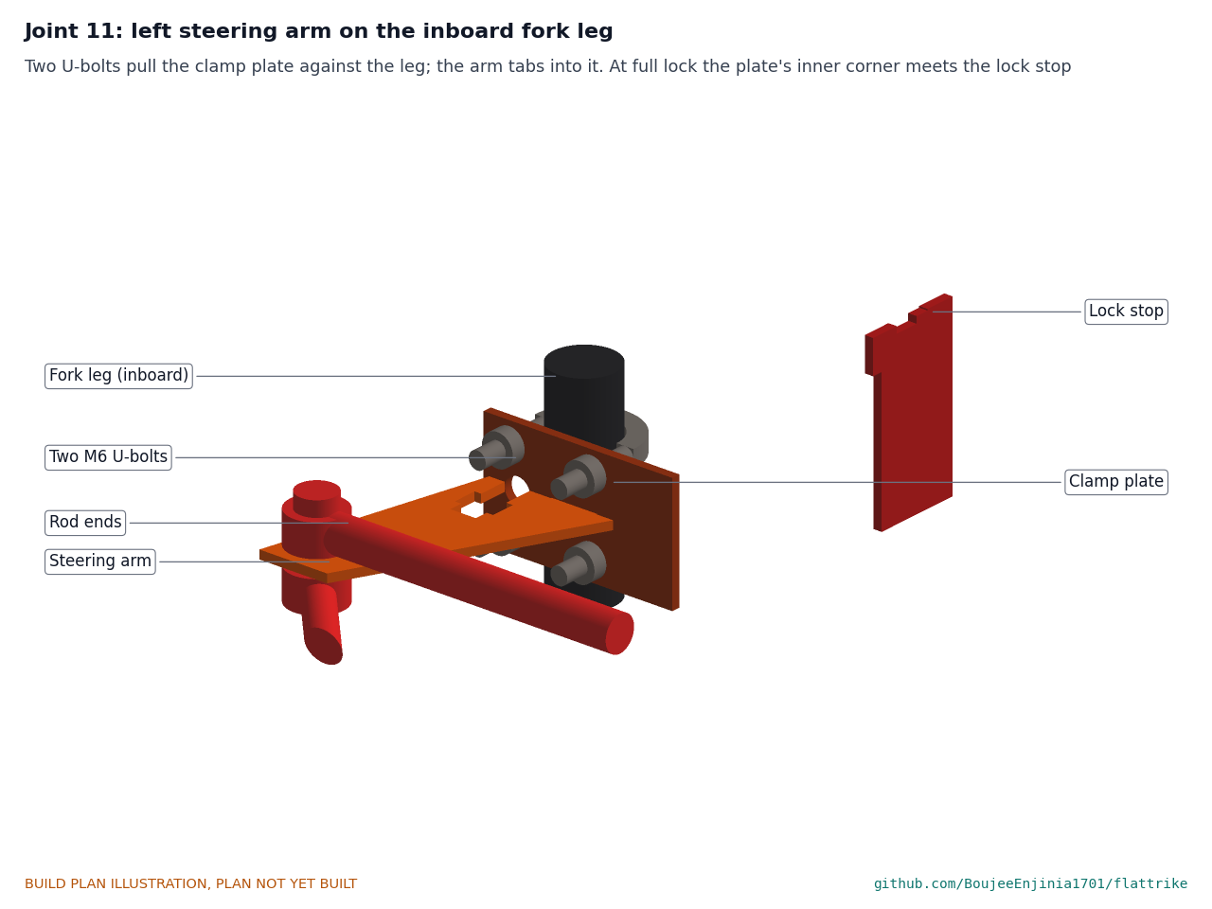
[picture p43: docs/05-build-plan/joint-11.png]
Figure 36. Joint 11: steering arm on the inboard fork leg


*Figure 36. Two M6 U-bolts go round the leg from the front and pull the clamp plate against it; the arm tabs and bolts into the plate. The drag link's rod end is under the left arm and the tie rod's on top.*

The arm sits 321 mm up, under the knuckle post, and turns with the wheel. The red fin ahead of the clamp plate is the lock stop.

**Check before moving on.** The U-bolts' legs pass through the plate without forcing.

### 3.24 Steering lock stops (make 2)

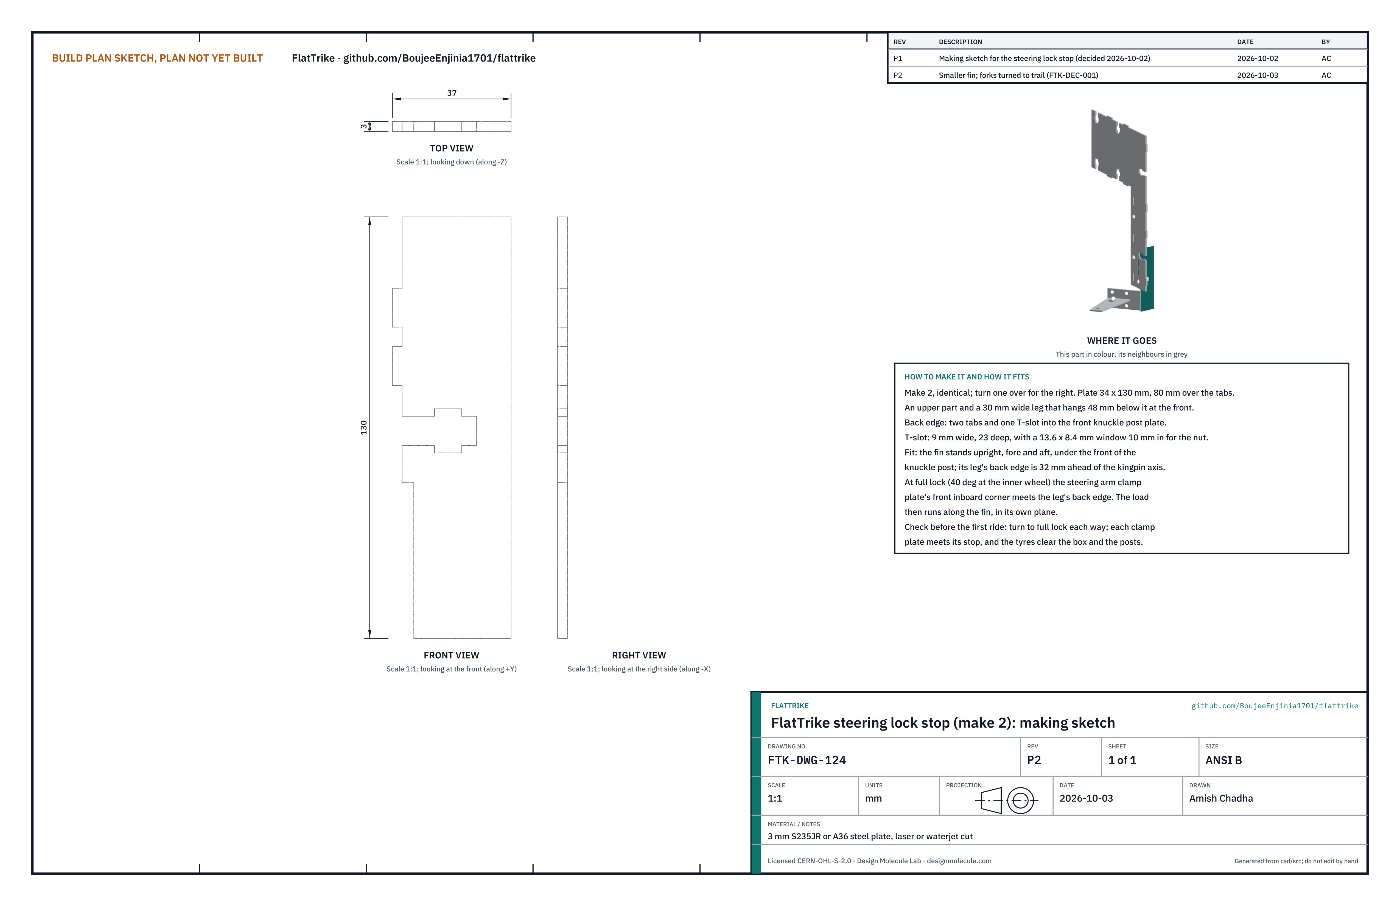
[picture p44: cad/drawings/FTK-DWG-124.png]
Figure 37. Making sketch of the steering lock stop


*Figure 37. Steering lock stop making sketch (FTK-DWG-124). The grey clamp plate and steering arm are drawn at full lock, where the clamp plate meets the stop.*

**What it is and what it is made from.** An upright fin under the front of each knuckle post that stops the steering at full lock, so the tyres cannot be turned into the box or the posts. 3 mm steel, 34 x 130 mm: a short upper part and a 30 mm wide leg that hangs down at the front.

**How to make it.** Deburr. Both are the same; turn one over for the right-hand post.

**How it fits the parts next to it.** Two tabs on its back edge go into the slots low on the front knuckle post plate, and one M8 bolt through the post plate screws into a T-slot in the fin (step 13). The fin stands fore and aft. When the inner wheel reaches 40°, the front inner corner of that wheel's steering arm clamp plate meets the back edge of the fin's leg, so the load runs along the fin in its own plane (Figure 36).

**Check before moving on.** The fin stands square to the post plate. After step 17, turn to full lock each way: each clamp plate meets its stop, and the tyres clear the box and the posts.

### 3.25 Cargo box

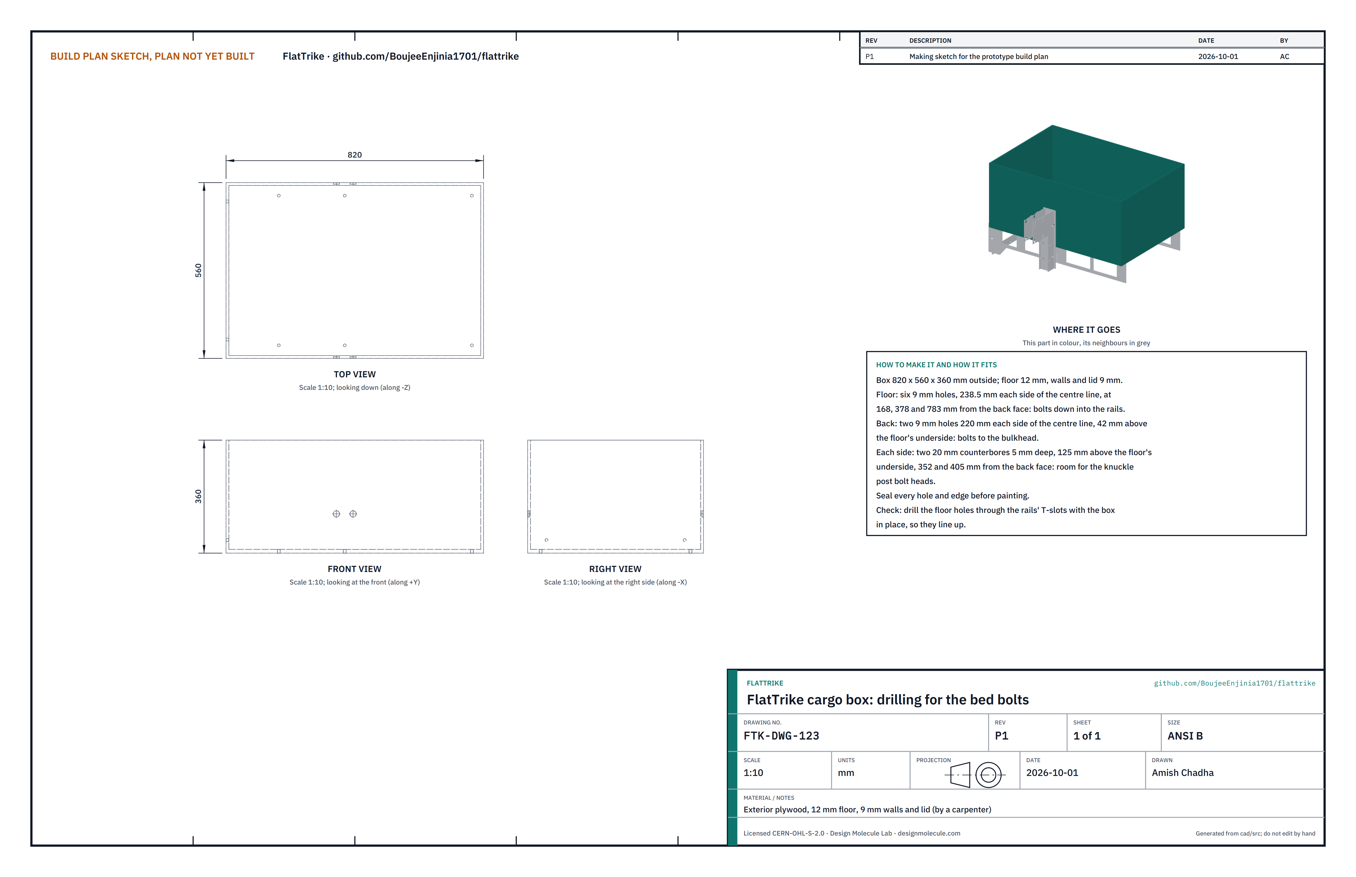
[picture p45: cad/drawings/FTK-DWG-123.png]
Figure 38. Drilling sketch of the cargo box


*Figure 38. Cargo box drilling sketch (FTK-DWG-123).*

**What it is and what it is made from.** A lockable exterior plywood box, 820 x 560 x 360 mm outside, 12 mm floor, 9 mm walls and lid, made by a carpenter. The lid is the counter.

**How to make it.**

1. Have the carpenter build the box, hinge the lid and fit the hasp.
2. Drill two 9 mm holes in the back, 220 mm each side of the centre line, 42 mm above the floor's underside.
3. Drill two 20 mm counterbores 5 mm deep in each side, 125 mm above the floor's underside, 352 and 405 mm from the back face, for the knuckle post bolt heads.
4. The six floor holes are drilled at step 20 through the rails' T-slots, so they line up.
5. Seal every hole and edge and paint the box.

**How it fits the parts next to it.**

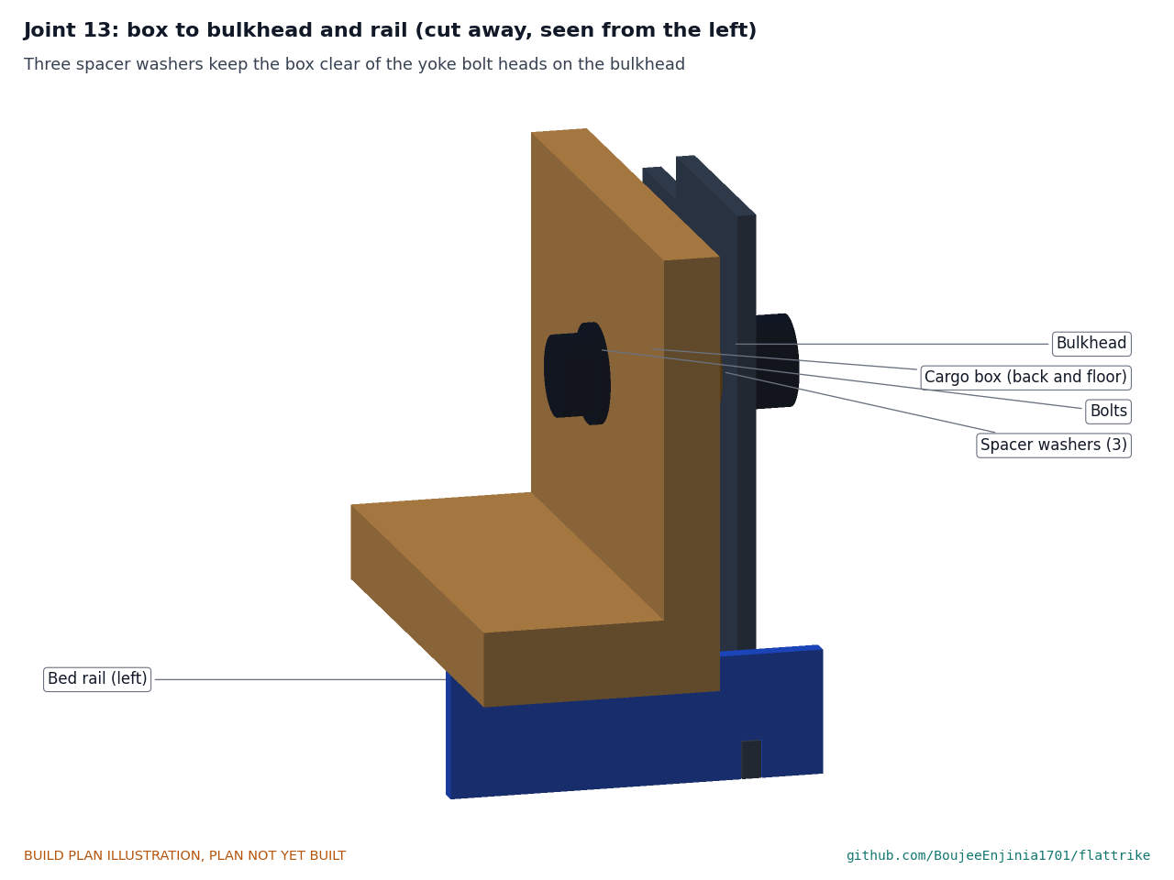
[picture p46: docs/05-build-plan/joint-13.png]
Figure 39. Joint 13: box to bulkhead and rail


*Figure 39. Three spacer washers keep the box 9 mm off the bulkhead, clear of the yoke bolt heads; floor bolts go down into the rails.*

**Check before moving on.** The box sits flat on the rails and beams with the lid closed and locked.

### 3.26 Bought components

Buy to specification, not brand. Line numbers are those of the bill of materials.

- **Plate (lines 1 to 4).** One 1,250 x 2,500 x 3 mm sheet of S235JR or A36 steel, cut by a laser or waterjet shop from the model's outlines with the washers in the windows.
- **Fasteners (lines 3, 4 and 5).** 97 sets of M8 class 8.8 zinc-plated bolts with washers and all-metal prevailing-torque locknuts: 80 at 25 mm for the tab joints and the two lock stops, eight at 35 mm for the box, four at 140 mm for the stay bolts, two at 45 mm for the drop arm and three at 40 mm for the rod ends; four M6 U-bolts for a 22 mm fork leg.
- **Steering (line 5).** Three 1 1/8 in threaded headsets; two 20 in steel forks for 100 mm hubs with a threaded 1 1/8 in steerer and straight BMX-type legs that run parallel to the steerer, 30 to 40 mm offset (a bent-leg fork will not do: the steering arm clamps to a straight leg); one 1 1/8 in threaded fork with a forged crown for the column; a tall quill stem (about 350 mm quill); three M8 rod ends with at least ±10° misalignment, on a drag link and a tie rod.
- **Front wheels (line 6).** Two 20 x 2.125 in (ISO 406) wheels with drum brake hubs 100 mm over locknuts, hub bodies 90 mm across or less.
- **Rear wheel (line 7).** 20 x 2.125 in with a 3-speed drum brake hub, 120 mm over locknuts, 24T sprocket and shifter.
- **Drivetrain (line 8).** Square-taper cartridge bottom bracket for a 68 mm shell, 170 mm cranks, 32T chainring, 1/8 in chain, pedals, chain guard.
- **Seat (line 10).** 31.8 x 2.3 mm seat tube, two 32 mm shaft collars, seat clamp, 27.2 mm seatpost, sprung saddle.
- **Bars and brakes (lines 11 and 12).** Steel riser bar and grips; two brake levers with a parking lock on the front pair; a cable splitter for the two front drums; cables and housing.
- **Finish and accessories (lines 13 and 14).** Zinc-rich primer and enamel or powder coat; mudguards, reflectors, bell, box bumpers and the cornering-speed label.

## 4. Putting it together

In each picture the parts already fitted are grey and the parts being fitted are in colour, with an arrow showing the way they go in. Tighten every M8 bolt to 25 N·m once its sub-assembly is square, unless a step says otherwise.

### Step 1: ribs, saddles and upper yoke into the left side plate

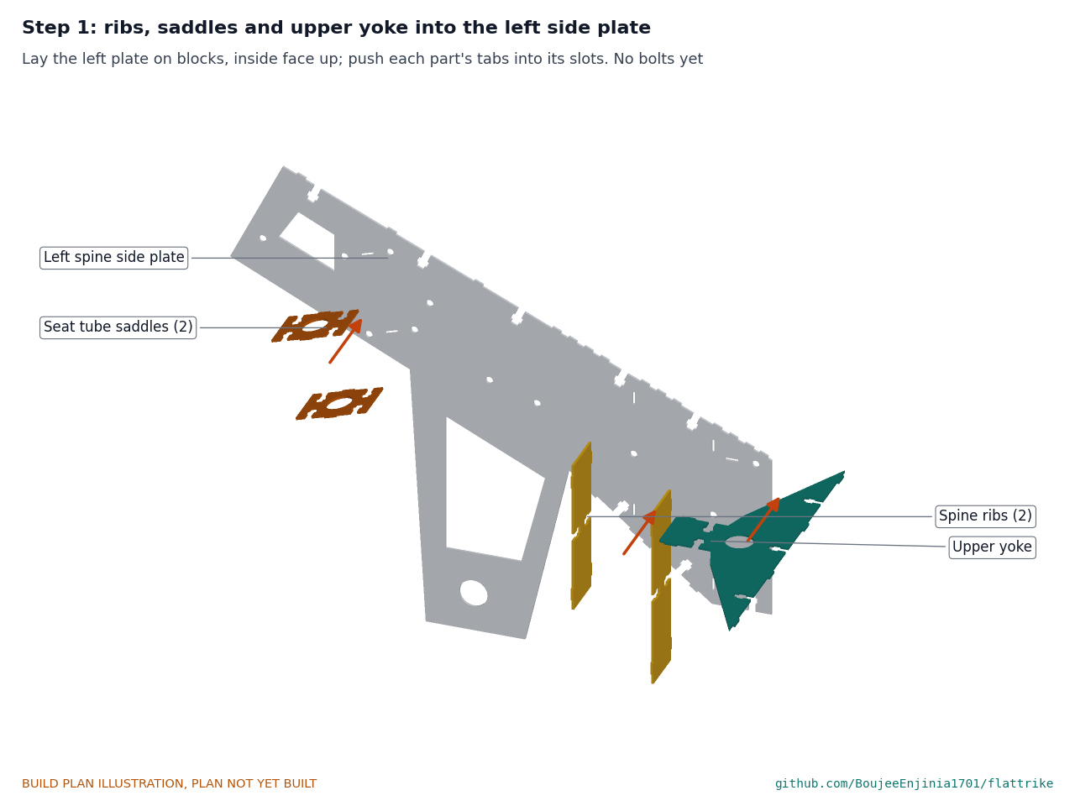
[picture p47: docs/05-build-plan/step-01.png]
Step 1


Lay the left plate inside face up on blocks. Push each rib, saddle and the upper yoke's tabs into its slots. No bolts yet.

### Step 2: right side plate onto the tabs

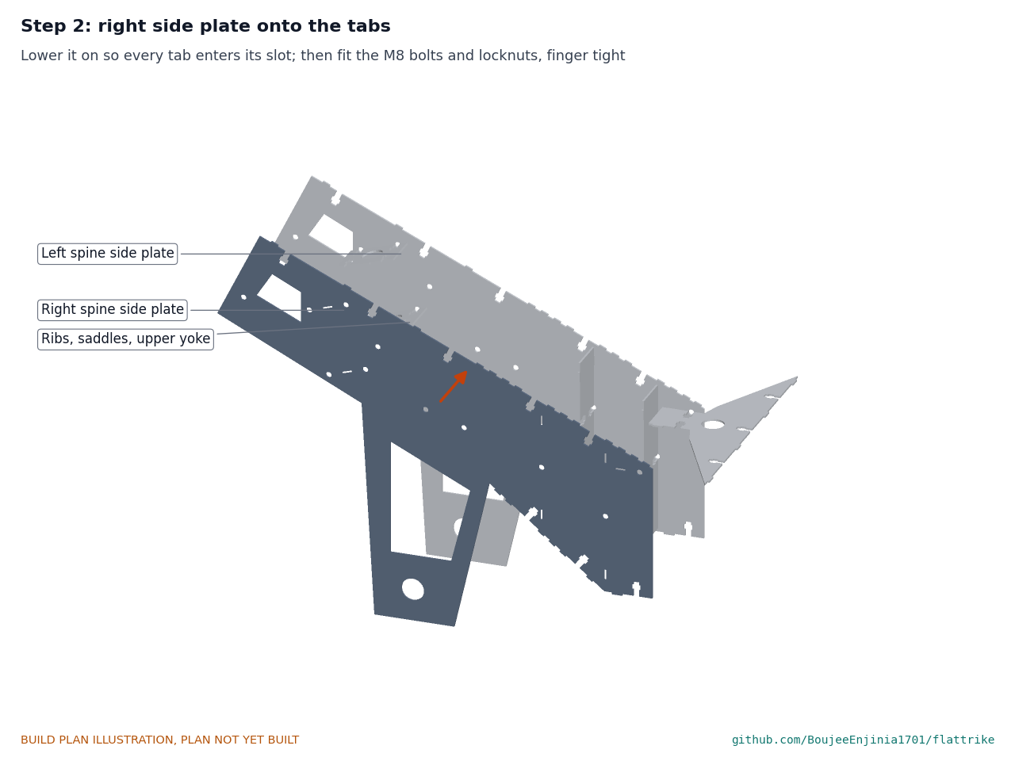
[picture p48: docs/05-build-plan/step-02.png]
Step 2


Lower the right plate on so every tab enters its slot; tap it down with a soft mallet. Fit the bolts and locknuts finger tight.

### Step 3: top cover

Step 3

Onto the plates' top-edge tabs; M8 x 25 bolts down into the T-slots with a locknut in each window.

### Step 4: bottom cover and lower yoke

Step 4

Up onto the bottom-edge tabs; bolts up into the T-slots. **Hold point:** measure the spine's diagonals and check it is not twisted on a flat floor, then tighten all its bolts.

### Step 5: head tube between the yokes

Step 5

Slide the 200 mm tube in between the yokes and line it up with their holes. Press the lower and upper headset cups in through the yokes with a headset press until each flange is hard against its yoke.

### Step 6: bottom bracket

Step 6

Hold the shell between the plates; screw the cups in from each side, the drive-side cup (left-hand thread) on the right, to the maker's torque.

### Step 7: seat tube

Step 7

Down through the top cover and both saddles, with the upper collar threaded on above the upper saddle as it passes. Tighten the collars against the saddles.

### Step 8: stay bridge between the stays

Step 8

Stand the stays 120 mm apart, bridge tabs in their slots, one bolt each side.

### Step 9: stays onto the spine

Step 9

Four M8 x 140 bolts: nine washers each side between spine and stay, a spacer tube inside the spine, a locknut on the far side. Check both dropouts line up across the trike before tightening.

### Step 10: bulkhead onto the yokes

Step 10

Onto both yokes' front tabs; bolts through the bulkhead into the yokes' T-slots.

### Step 11: bed rails onto the bulkhead

Step 11

Each rail onto the bulkhead's side tabs and against the lower yoke's front corner; one bolt each into the bulkhead's T-slot.

### Step 12: axle beams up into the rails

Step 12

Push each beam plate up from below so its slots straddle both rails and the rails sit in the beam's slots. Tap them home until all top edges are level.

### Step 13: build each knuckle post (left shown)

Step 13

Post plates into the inner cheek, outer cheek between the plates, collar plates on top and bottom, all bolted finger tight; slide the 120 mm head tube in between the collar plates and press its cups in. Push the lock stop's tabs into the slots low on the front post plate and fit its bolt. Then tighten.

### Step 14: knuckle posts onto the axle beams

Step 14

Each post, with its lock stop on the front plate, goes onto the beams' end tabs, inner cheek first; bolts through the cheek into the beams. **Hold point:** with a straight edge across both knuckle head tubes, check they are parallel and plumb, and the posts are 840 mm apart centre to centre.

### Step 15: steering column and drop arm

Step 15

Crown race onto the crown; steerer up through the head tube; adjust the headset so the column turns freely with no play. Bolt the drop arm under the crown.

### Step 16: front forks and wheels

Step 16

Turn each fork round so its legs are **behind** the steerer, not in front of it as on a bicycle; then its steerer goes up through its knuckle head tube. Adjust the headsets; fit the wheels in the dropouts with the drum brake reaction arms clipped to the legs. **Hold point:** each axle is 30 to 40 mm behind its knuckle head tube's centre line (a plumb line from the head tube centre lands ahead of the axle).

### Step 17: steering arms onto the fork legs

Step 17

Clamp plate behind each inboard leg, 303 to 343 mm up, long end pointing in; two U-bolts round the leg from the front; arm tabs into the plate, one bolt. **Hold point:** turn the wheel to full lock each way; the clamp plate's front inner corner meets its lock stop (red) with the inner wheel at 40°, and nothing else touches.

### Step 18: tie rod and drag link

Step 18

Drag link's rod end under the drop arm's tip and under the left steering arm; tie rod's rod ends on top of both steering arms; locknuts on all three bolts. Set the tie rod's length so both wheels point straight ahead with the handlebar square, then set the U-bolts tight. **Hold point:** turn from full left to full right lock: nothing may touch.

### Step 19: rear wheel and drivetrain

Step 19

Axle into the open dropouts with the hub's non-turn washers; chainring, cranks and pedals on; chain on; pull the wheel back to tension the chain, then tighten the axle nuts. Set the hub gear's cable.

### Step 20: cargo box onto the bed

Step 20

Box on the rails and beams, three spacer washers on each back bolt. Drill the six floor holes through the rails' T-slots, then fit the floor bolts with penny washers and the two back bolts.

### Step 21: seatpost, saddle, handlebar and brakes

Step 21

Seatpost and saddle in the seat tube; quill stem and bar in the steering column; brake levers, cables, the front cable splitter and the parking latch; the cornering-speed label on the bar.

## 5. First checks

These are the checks a TRL 4 test report would record; this plan only lists them. Requirement numbers are those of FTK-REQ-001.

*Table 2. First checks.*

| Check | Requirement | How | Pass when |
| --- | --- | --- | --- |
| Joints closed | R3, R7 | Look at every tab and bolt; record the time the build took | Every tab seated; every bolt at 25 N·m with a locknut; build time recorded against 4 h |
| Frame square | R2 | Diagonals of the spine and bed; wheel alignment with a string line | Diagonals within 3 mm; front wheels parallel to the rear within 2 mm over their diameter |
| Steering | R9, R10 | Turn lock to lock; measure each wheel's angle; mark the turning circle on the ground | Nothing touches; each steering arm clamp plate meets its knuckle post stop at 40°; each axle trails its head tube by 30 to 40 mm; let go of the bar while rolling slowly and it returns toward straight ahead; outer tyre circle 6 m or less |
| Empty mass | R8 | Weigh the trike with its box | Recorded against 72 kg (71.6 kg estimated); sets the final load label |
| Proof load | R2 | At least twice the rated cargo (300 kg of sandbags, the R2 proof load of FTK-CAL-001) in the box, rider seat loaded with 80 kg, for 10 minutes | No permanent set: box floor and frame heights back within 1 mm after unloading; no tab moved in its slot |
| Parking brake | R11 | Loaded, on a 10 % slope, front pair latched | Does not move |
| Tipping | R10 | Tilt table, rider-only ballast | Tips at 0.22 g or more |
| Box | R17 | Lid height and inside volume | Lid 0.75 to 0.95 m; 150 L or more; locks |

## 6. Safety stops

Stop at each point. Carry on only when everything listed is true.

- **S1. Before handling cut plates.** Every plate deburred; cut-resistant gloves and safety glasses worn.
- **S2. Before pressing headset cups or drilling the crown.** The part is held in a vice or press, not by hand; the drill is a pillar drill with the crown clamped.
- **S3. Before the trike stands on its wheels.** Every M8 bolt tightened to 25 N·m with a locknut; every rod end bolt has its locknut; the U-bolts are tight; the headsets have no play.
- **S4. Before anyone sits on it.** The steering turns lock to lock without touching anything; all three brakes stop the wheel by hand; the parking latch holds; the chain guard is on.
- **S5. Before any load goes in the box.** S3 and S4 passed; the proof load is applied with the trike on a level floor, chocked, with nobody on it or beside the box.
- **S6. Before the first ride (outside this plan).** A steering lock stop is fitted at each knuckle post, met by its steering arm clamp plate at 40°; both knuckle forks are fitted turned round, so each axle trails its steering axis by 30 to 40 mm (a fork fitted as sold makes the steering pull into turns); the steering geometry is repeated on paper with the chosen fork's measured offset; the proof load is passed with no permanent set; the rider rides slowly on closed private ground, empty first, keeping to 6 km/h in full-lock turns; never on a public road until R2 is verified.

## 7. Tools, skills and workspace

**Tools.** A laser or waterjet cutting shop for the plates and washers. Files, a deburring tool and a scraper; hacksaw or bandsaw; pillar drill with 9 mm and 20 mm drills; tape, steel rule, engineer's square, calipers and a digital angle finder; soft mallet; spanners and sockets to 17 mm, hex keys, M8 torque wrench covering 10 to 40 N·m; bicycle tools: headset press, head tube facing tool (or a bicycle workshop), crown race setter, bottom bracket tool, crank puller, cone spanners, chain tool and cable cutters; a straight edge and string line for alignment; two trestles.

**Skills.** No certified trade is needed. Basic metalwork (deburring, sawing, drilling, filing) and a bicycle mechanic's skills: headsets, bottom brackets, hub gears, drum brakes and cables. Two people for steps 2, 9, 14 and 20.

**Workspace.** A level floor about 3 x 2 m, a bench with a vice, and a clear area of 6 m diameter to check the turning circle.

**Personal protective equipment.** Cut-resistant gloves for plate handling; safety glasses for cutting, filing and drilling; hearing protection when sawing; no gloves near a turning drill.

## 8. Where the numbers come from

- Model and constructability checks: `cad/src/model.py` (`python cad/src/model.py --check`); STEP and STL exports in `cad/step/` and `cad/stl/`.
- Pictures: `cad/src/build_plan_media.py`, using `.kit/build_views.py`; written to `docs/05-build-plan/` and `cad/drawings/FTK-DWG-101` to `FTK-DWG-124`.
- General arrangement: `cad/drawings/FTK-DWG-001.pdf`, Rev P5.
- Calculations: `docs/04-calcs/01-sizing.md` (FTK-CAL-001 v0.7), `docs/04-calcs/sizing.py` and `docs/04-calcs/results.csv`.
- Bill of materials: `bom/bom.csv` and `bom/bom-notes.md`.
- Decisions: `docs/decisions/0003-design-for-construction.md` (FTK-DDR-003), with FTK-DDR-001 and FTK-DDR-002; decisions of 2026-10-02 in `docs/06-design-decisions.md` (FTK-DEC-001).
- Requirements: `docs/03-requirements.md` (FTK-REQ-001).

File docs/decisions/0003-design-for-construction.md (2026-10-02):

---
doc_id: FTK-DDR-003
title: FlatTrike design for construction
project: FlatTrike
doc_type: Design decision record
version: "0.3"
status: Draft
date: '2026-10-02'
author: Amish Chadha
license: CERN-OHL-S-2.0
revisions:
- version: "0.1"
  date: '2026-10-01'
  author: Amish Chadha
  change: Changes that make the concept physically buildable, with the reason for each; made under Amish's 2026-09-30 instruction to make the design physically buildable; open for his review
- version: "0.2"
  date: '2026-10-01'
  author: Amish Chadha
  change: Budget treated as a value-engineering target
- version: "0.3"
  date: '2026-10-02'
  author: Amish Chadha
  change: "Accepted by Amish on 2026-10-02, including the recommendations for A1 to A3"
---

# 0003: Design for construction

- **Date:** 2026-10-01
- **Status:** accepted. Amish, 2026-10-02: "i approve your recommendations for all 555 open decisions." This covers every change in Tables 1 and 2 and the recommendations for A1 to A3 in Table 3, which are now decided as recommended and recorded in the design decisions register (FTK-DEC-001).

## Context

On 2026-09-30 Amish asked for a build plan that shows how each component is made and how it fits the next, and wrote: "If you are realising that the design cannot be built as per concept - fix the design assumptions to match and be physically feasible as you draw the illustrations." The TRL 3 model of FTK-DDR-002 showed what FlatTrike does and passed its calculations, but it modelled the plates as loose shapes: none of the tabs, slots or bolts the precis describes were drawn, and checking the model with build123d found parts that cut through each other, joints with no material for a bolt, a steering linkage that locks, and steering arms that hit the frame.

`cad/src/model.py` now builds every piece as its own solid (35 cut plates, the bought parts and 95 bolt sets) and runs constructability checks (`python cad/src/model.py --check`): every tab, slot, bolt hole and T-slot lies on solid plate with at least about 5 mm of material round it; no two pieces overlap; every piece touches the assembly; and the wheels, forks, steering arms, drag link, tie rod and steering column are swept from full left to full right lock without touching the fixed structure. All checks pass.

The changes keep what the trike does: the same layout, wheelbase, track, wheels, seat position, box size and height, Ackermann steering with a fixed box, flat 3 mm plates cut from one sheet, and no welding or bending. Nothing here changes the pitch. Two consequences touch requirements (Table 3).

## Decision

*Table 1. Changes made to the model, the BOM and the calculations.*

| # | Problem in the concept | Change made | Why this way |
| --- | --- | --- | --- |
| P1 | No joints were modelled. The spine covers were exactly as wide as the spine, so a bolt through a cover into a side plate's edge would break out of the cover's edge; the ribs, yokes and covers had nothing holding them. | One joint for every place where a plate's edge meets another plate's face: tabs on the edge sit in slots in the face (they carry the load), and between tabs an M8 bolt passes through the face into a T-slot in the edge, where an all-metal locknut sits in a window and cannot turn. The covers are 90 mm wide (12 mm past each side plate). In the closed part of the spine box the tabs are 22 mm apart, ten per edge. | It is the tab-and-slot joint the precis describes, made physical, and it keeps the decided M8 8.8 bolts and all-metal locknuts (FTK-DDR-001 item 5). Ten tabs per edge give the 87 MPa tab bearing stress the calculation note already assumed. |
| P2 | Two of the four stay-to-spine bolts passed through the spine's rear lightening window, so they bore on nothing; a bolt across the spine had nothing to stop it squeezing the side plates together. | Rear bolts moved to 335 mm ahead of the rear axle, 697 mm up, and 545 mm, 650 mm up; a smaller rear window clear of them; a 60 mm spacer tube (16 x 2 mm steel tube) inside the spine on every stay bolt. | Every bolt now clamps solid plate; the truss nodes of the stay calculation move by less than 10 mm. |
| P3 | The rear dropout was a closed rectangular hole: the wheel could not be fitted. | An open slot 10 mm wide cut into the stays' rear edge, the axle 53 mm from its mouth; the wheel slides in from behind and moves back to tension the chain. | As on any bicycle with a hub gear. |
| P4 | The chain was on the rider's left. | Moved to the right, at the same 44 mm chain line. | Standard cranks, bottom brackets and hub gears are right-hand drive. |
| P5 | The bottom bracket shell passed through holes in both side plates with "bolted collars" that were not drawn. | The shell is 60 mm long and sits between the side plates; each bottom bracket cup screws in through a 35.5 mm hole and its flange clamps the plate against the shell's end. | Uses the bought cups as the clamp; no collars. |
| P6 | The seatpost stood in the open spine with no tube or clamp. | A bought 31.8 x 2.3 mm seat tube, 225 mm long, passes through an oval hole in the top cover and through two cut saddles across the spine, with a shaft collar on the outside of each saddle; the 27.2 mm seatpost clamps in it. The rearmost spine rib (at 380 mm) is gone: the saddles are now the cross plates there. | The seat line, saddle height and position are unchanged. |
| P7 | The head tube collar plates cut through the spine side plates; the lower yoke sat where the steering fork's crown and lower headset are; the eight yoke-to-collar bolts were not placed. | The yokes are now the head tube's clamp plates: the 200 mm head tube is exactly the gap between them, and each pressed headset cup passes through a 34.5 mm hole in its yoke and clamps the yoke to the tube's end. The upper yoke tabs into both side plates; the lower yoke lies under a new 75 mm level edge at the bottom of the spine's front. The two head tube collar plates are gone. | Fewer parts, and the roll couple at the head tube (2.58 kN at 0.5 g) passes through the cups into the yokes and through the yokes' tabs into the spine (27 MPa bearing). |
| P8 | The steering column had no lower bearing seat and no way to fix the drop arm. | The column is a bought threaded fork with a forged crown, legs sawn off at the crown, and a tall quill stem; the drop arm bolts flat under the crown with two M8 bolts drilled through it. | The crown carries the lower bearing race; two bolts make the drop arm rigid. |
| P9 | The steering linkage locked: with a 70 mm drop arm pointing sideways, no column angle could follow the left steering arm past about 10° of right turn. | The drop arm is 120 mm long and parallel to the left steering arm, so column, drop arm, drag link and left arm form a parallelogram. The handlebar turns as far as the left wheel; full lock is 40° each way. | Works through the whole range; the drag link now runs well below the bulkhead and rails. |
| P10 | The steering arms had no fixing to the forks. At the concept height (400 mm) they swept the space beside the knuckle post columns, passing within a few millimetres at full lock, and into the columns once the posts moved in (P11). | The arms are 321 mm up, below the knuckle posts, each tabbed and bolted into a clamp plate that two M6 U-bolts hold against the inboard fork leg. The knuckle posts and axle beams now start 350 mm up (were 290 mm), so the beams are 120 mm deep (were 180 mm) and the arms, tie rod and drag link pass beneath them. | The steering sweep check passes from lock to lock. Axle beam stress rises from 16 to 36 MPa, still low. |
| P11 | The knuckle collar plates carried each wheel's load in bending across a 90 mm span (over 200 MPa by a simple beam estimate); the knuckle posts' corners were flush, with no room for bolts; the fork crown would hit the post plates at lock. | The two post plates stand 25 mm either side of the knuckle head tube (were 45 mm), so each cup flange bears on its collar plate within 2.5 mm of the plates and the load goes straight into them. The inner cheek is a 76 mm face plate the post plates tab into; the outer cheek sits 10 mm in from the plates' outer edges. Above the tyre the plates step out of the fork crown's path. | The cheeks still close the column: column stress 40 MPa (was 47 MPa). The tyre clears the post by 36 mm at full lock (was 19 mm). |
| P12 | The upper yoke met the bulkhead in its window; the rails began at the bulkhead, leaving no plate round the bulkhead's slots. | The bulkhead window is split into two, with solid plate where both yokes meet it; the rails start 20 mm behind the bulkhead; the bulkhead's bottom edge is 6 mm higher (298 mm) to clear the steering fork crown and the drag link. | Every slot has solid plate round it. |
| P13 | The rails and axle beam plates passed through each other, and the beams' windows sat where the rails cross. | Halving joints: a 55 mm slot up from the rail's bottom edge, a 55 mm slot down from the beam's top edge. The beam windows are moved clear of the crossings; the rails' rear lower edge is raised to 310 mm. | The box floor sits on both and holds the halvings closed. |
| P14 | The box had no fixing to the bed, and bolt heads on the bulkhead's front face would have stood in the box's back. | Six M8 bolts down through the floor into T-slots in the rails' top edges, and two through the back into the bulkhead on stacks of three spacer washers, so the box stands 9 mm in front of the bulkhead. Two 20 mm counterbores 5 mm deep in each box side clear the knuckle post bolt heads. | The box size and floor height are unchanged; the trike is 9 mm longer (2.146 m). |
| P15 | The front hubs were 106 mm long in 100 mm forks. | Hubs 100 mm over locknuts, as bought for 100 mm forks. | Matches the bought parts. |

*Table 2. Knock-on changes.*

| Item | Change | Reason |
| --- | --- | --- |
| Plates | 35 plates (was 34): two seat tube saddles, two clamp plates added; one rib and two head tube collar plates removed. 78 spacer washers (was 72). 95 bolt sets (was 116). True-shape nest 1,940 mm of the 2,500 mm sheet (was 2,190 mm). | P1 to P14. |
| Mass | Empty 71.2 kg (was 69.8 kg): plates 30.5 kg (was 29.4 kg), the seat tube, collars, spacer tubes and U-bolts 0.75 kg, fewer bolts 0.5 kg lighter. | Wider covers, solid plate round every joint, the bought parts above. See Table 3. |
| Structure | Stay buckling safety factor 2.01 (was 2.09); axle beam 36 MPa; knuckle post column 40 MPa; knuckle post arm 16 MPa; tab bearing 87 MPa; yoke tab bearing 27 MPa. | FTK-CAL-001 v0.3. R2 stays at risk. |
| Steering | Outer wheel 31.3° at 40° inner lock through the real tie rod (ideal Ackermann 29.5°); handlebar turns 1:1 with the left wheel. | P9; the turning circle calculation still uses ideal Ackermann. |
| Assembly and repair | Assembly about 4.04 h for two people (was 4.00 h); a spine side plate about 80 min (was 78 min); a knuckle post plate about 53 min (was 27 min), because both collar plates and the headset cups must come off to release it. | See Table 3. |
| Cost | BOM lines 4, 5, 10 and 11 respecified and repriced: pedal-only prototype $724 (was $709), USD 76 under the unchanged $800 value-engineering target (`budget_usd`). | Seat tube and collars, U-bolts, the cut-down steering fork and a tall quill stem. |
| Drawings | FTK-DWG-001 Rev P3; making sketches FTK-DWG-101 to 123 added. | Follows the model. |
| Renders | `media/render-*.png`, `media/card.png`, `media/social-preview.png` and the appearance model `cad/src/product_model.py` still show the concept (chain on the left, collar plates, steering arms at 400 mm, wider knuckle posts). They need updating on Amish's Mac. | Not regenerated here. |

*Table 3. Items that change a requirement or the rated load: proposed, then accepted by Amish as recommended on 2026-10-02.*

| # | Question | Options | Recommendation |
| --- | --- | --- | --- |
| A1 | R1 and R8 now fail by 1.2 kg: empty 71.2 kg against 70 kg, gross 301.2 kg against 300 kg with the rated loads. | (a) rate the cargo at 148 kg with a rider up to 80 kg and 138 kg with a rider up to 90 kg, keeping the 300 kg class, and relax R8 to 72 kg; (b) keep 150 and 140 kg and look for 1.2 kg (lightening windows in the knuckle post arms and yokes, about 0.5 kg, and a lighter box); (c) both. | (c): adopt (a) now so the stated rating is true, and try (b) in the FEA session; the final load label is set from the weighed trike. Accepted 2026-10-02. |
| A2 | R14: a knuckle post plate now takes about 53 min to replace against 30 min. | (a) allow 60 min for knuckle post plates, as for the spine side plates; (b) redesign the post so a plate comes out without the collar plates. | (a). Accepted 2026-10-02. |
| A3 | R7: assembly is about 4.04 h against 4 h. | (a) accept, time it at TRL 4; (b) relax R7 to 4.5 h. | (a): the estimate is within its own accuracy of the target. Accepted 2026-10-02. |

## Consequences

- `design_state: constructable` in `project.yaml`. The build plan FTK-BLD-001 shows every component and step in pictures generated from the model (`cad/src/build_plan_media.py`); the open items are in the design decisions register FTK-DEC-001.
- Requirement status (FTK-CAL-001 v0.3): R1 and R8 not met by 1.2 kg (A1); R7 at the limit (A3); R14 not met for the knuckle post plates (A2); R13 not met as before and R18 over its value-engineering target as before; R2 and R11 at risk; R16 not verifiable at TRL 3.
- With A1 accepted, the rating is 148 kg of cargo with a rider up to 80 kg or 138 kg with a rider up to 90 kg (gross 299.2 kg) and R8 is 72 kg, so R1 and R8 are met on paper; with A2 accepted, R14 allows 60 min for a knuckle post plate and is met on paper (53 min); with A3 accepted, R7 stays at risk and is timed at TRL 4. FTK-CAL-001's script still states the old targets until it is updated (register, follow-up actions in `docs/REVIEW.md`).
- Parts to confirm when bought are listed in the register: the steering fork with a forged crown, the tall quill stem, the rod ends' misalignment, the hub axle lengths and the U-bolts' grip on the fork legs.

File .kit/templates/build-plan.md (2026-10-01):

---
doc_id: PRJ-BLD-001
title: Project prototype build plan
project: Project name
doc_type: Build plan
version: "0.1"
status: Draft
date: YYYY-MM-DD
author: Amish Chadha
license: CERN-OHL-S-2.0
revisions:
  - version: "0.1"
    date: YYYY-MM-DD
    author: Amish Chadha
    change: First build plan; design made constructable
---

# Project prototype build plan

**Plan, not yet built.** How to build the first proof-of-concept prototype, component by component. Building and testing to it is TRL 4 work. Decisions still to be made are kept in the design decisions register (`docs/06-design-decisions.md`), not here.

## 1. What you are building

Every component, pulled apart and numbered in build order

One short paragraph: what the prototype is, how many components, which are made and which are bought, and the main ways they are made.

## 2. What changed to make it buildable

| Component | The concept had | The buildable design has | Why |
| --- | --- | --- | --- |

## 3. Making the components

### 3.1 Component name

Making sketch

**What it is and what it is made from.**

**How to make it.**

1. Mark out ...
2. Cut ...

**How it fits the parts next to it.**

Close-up of the joint

**Check before moving on.**

## 4. Putting it together

### Step 1: ...

Step 1

## 5. First checks

| Check | Requirement | How | Pass when |
| --- | --- | --- | --- |

## 6. Safety stops

## 7. Tools, skills and workspace

## 8. Where the numbers come from

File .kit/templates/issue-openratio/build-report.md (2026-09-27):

---
name: Build report
about: Tell us what happened when you built, printed or tested part of this design
title: "Build report: "
labels: build-report
---

This is a research and educational prototype, not a medical device. It is a TRL 3 concept and is not released for fabrication. If you build any part of it, you do so at your own risk. Reports help everyone.

**What you built** (part, sub-assembly or test)

**Materials, tools and settings**

**What worked**

**What did not work, with photos or measurements if you have them**

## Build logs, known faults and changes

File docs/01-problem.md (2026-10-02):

---
doc_id: FTK-PRB-001
title: FlatTrike problem statement
project: FlatTrike
doc_type: Problem statement
version: "0.5"
status: Draft
date: '2026-10-02'
author: Amish Chadha
license: CERN-OHL-S-2.0
revisions:
- version: "0.1"
  date: '2026-09-24'
  author: Amish Chadha
  change: Initial scaffold
- version: "0.2"
  date: '2026-09-25'
  author: Amish Chadha
  change: Populate to TRL 2 (users, context, constraints, out of scope, prior work with sources)
- version: "0.3"
  date: '2026-09-25'
  author: Amish Chadha
  change: Record TRL 2 review decisions (FTK-DDR-001); production cost target; open questions updated
- version: "0.4"
  date: '2026-09-25'
  author: Amish Chadha
  change: Recommendations accepted by Amish (DDR-002)
- version: "0.5"
  date: '2026-10-02'
  author: Amish Chadha
  change: "Rated cargo restated (148 and 138 kg) and partner selection rule recorded, decisions of 2026-10-02"
---

# FlatTrike problem statement

Street vendors and micro-logistics operators in emerging markets need durable cargo tricycles, but imported units are expensive and hard to repair, and the locally built alternatives are heavy, flexible and short-lived. FlatTrike aims at the gap between the two: a cargo tricycle whose steel frame is cut from flat plate by any laser or waterjet shop from open files, bolts together without welding, uses standard bicycle parts, and ships flat. Design with, not for: requirements must come from co-design sessions and field trials with the intended users through a local partner.

## The problem

Street vending and small-scale carrying are among the largest sources of urban self-employment in South Asia, sub-Saharan Africa and Latin America. India alone has an estimated 10 million street vendors, a figure based on about 2.5 % of the urban population ([Observer Research Foundation](https://www.orfonline.org/research/strengthening-urban-india-s-informal-economy-the-case-of-street-vending)). Many of them, and many porters, recyclers and delivery riders, depend on a pedal tricycle or push cart to move 100 to 300 kg of goods every day.

Two kinds of cargo tricycle are on offer, and each fails these users in a different way:

1. **Local workshop tricycles** (loading rickshaws, *thelas* and vending trikes) are cheap, often ₹10,000 to ₹25,000 (about $120 to $300) in Indian online marketplaces ([IndiaMART listings](https://m.indiamart.com/impcat/cycle-rickshaw.html), accessed 2026-09-25). They are built from strengthened bicycle parts and mild steel sections. The Institute for Transportation and Development Policy (ITDP) found that the traditional cycle rickshaw weighs about 80 kg, that its bolted-on structure is "overly flexible and often misaligned", that it has a single gear, and that its wooden frame needs replacing every two to three years ([ITDP, 2006](https://itdp.org/2006/07/01/rickshaws-in-the-new-millennium/)). The rider pays for this in effort, in pushing on every hill and in repairs.
2. **Imported and branded cargo trikes** are lighter, geared and well braked, but cost many times more. Even an open design built under license, such as the XYZ Cargo space-frame bike, retails at about $1,860 ([Bike Hugger](https://www.bikehugger.com/posts/open-source-space-frame-cargo-bike/)). Spares are proprietary, and a broken frame usually means a new vehicle.

Better engineering is possible at low cost. ITDP's India Cycle Rickshaw Improvement Project cut the rickshaw's mass to about 55 kg with an integral tubular frame, added gears, and reported about 50 % higher earnings for operators at a similar price ([ITDP, 2006](https://itdp.org/2006/07/01/rickshaws-in-the-new-millennium/)). But a good tubular frame needs jigs and skilled welding, which is exactly what limits who can build and repair it.

The gap FlatTrike addresses is a frame that is precise without a jig and without welding. Laser and waterjet cutting shops are now common in industrial areas of most mid-sized cities. If the frame is a set of flat plates cut from open files, any such shop can make a new frame or a single replacement plate, and the precision comes from the cutting, not from the builder's skill.

## Users and context

| User | Need | Context |
| --- | --- | --- |
| Street vendor | Carry and display 100 to 150 kg of produce, snacks or goods; lock them up; sell from the vehicle | Daily trips of 5 to 20 km; parks for hours; crowded markets and narrow lanes |
| Micro-logistics operator | Deliver or collect goods (parcels, gas cylinders, water cans, recyclables) with the highest load per trip | Stop-start riding in traffic; 20 to 40 km a day; income depends on trips per day |
| Local laser or waterjet shop | Cut a full frame or one plate from open DXF files on a standard sheet | Industrial estate; 3 mm mild steel stock; no bicycle expertise |
| Bicycle mechanic or small fabricator | Assemble, maintain and repair the trike with hand tools and standard bicycle spares | Roadside or market stall; no welding in many cases |
| Cooperative or NGO | Buy frames in batches, train builders, lease trikes to vendors | Municipal vending zones and livelihood programs |

### Operating environment

- **Roads:** asphalt with potholes, speed bumps, broken paving and unpaved lanes; grades up to about 5 % on common routes and short ramps steeper.
- **Loads:** rider 60 to 90 kg; 100 to 150 kg of cargo, often stacked high; occasional overloading well beyond the rating.
- **Climate:** ambient 10 to 45 °C, monsoon rain, dust, coastal salt air in some cities; the vehicle is usually parked outdoors.
- **Use:** 6 to 7 days a week, several years of commercial service, frequent parking on slopes and curbs.
- **Supply chain:** bicycle spares (20 in wheels, 1 1/8 in headsets, 1/8 in chains, drum and hub-gear parts) are available in towns; laser cutting of 3 mm mild steel is available in most industrial areas.

## Constraints

- Garage-buildable pedal-only prototype for about $800 USD in parts (`project.yaml`); the optional electric assist and any SwapCell pack are outside this budget (decided by Amish, 2026-09-25, FTK-DDR-001).
- Production cost of $300 or less per trike at 100 units, so that the design can compete on value with local workshop tricycles (decided by Amish, 2026-09-25; FTK-REQ-001 R18). The target is kept until the first partner supplies wholesale prices (FTK-DDR-002).
- Gross mass of 300 kg or less, so the rated cargo is 148 kg with a rider up to 80 kg and 138 kg with a rider up to 90 kg (decided by Amish, 2026-09-25, FTK-DDR-002, and restated for the constructable design on 2026-10-02, FTK-DDR-003 A1).
- Every steel part is cut from flat sheet by laser or waterjet from open files. No welding.
- Joints are bolted with locknuts and can be taken apart and rebuilt.
- Moving parts (wheels, hubs, brakes, drivetrain, headset, seat) are standard bicycle parts available in regional markets.
- The frame ships flat and is assembled by the user, a mechanic or a cooperative.
- Mass, stiffness and durability must beat the local workshop tricycle, or it will not be adopted at any price.
- Cargo bike standard EN 17860 (in development since 2024) sets requirements for cargo cycles up to 300 kg gross, with stricter limits for commercial use ([ACT Lab](https://act-lab.com/cargo-bike-safety-en-17860/)); it is the reference for load cases even where it is not law.

## Out of scope

- Motor tricycles and petrol or high-power electric three-wheelers (auto-rickshaws, e-rickshaws).
- Passenger rickshaws; FlatTrike carries goods and one rider only.
- Designing a battery or motor. An electric assist option would use an existing kit (see FTK-PRC-001).
- Vending-specific fit-outs (cooking stations, refrigeration, awnings) beyond a lockable box whose lid serves as a counter.
- Heavy-duty cargo platforms such as CargoMule.

## Prior work

- **Traditional and improved cycle rickshaws.** ITDP's work in India documents the weight, flex and single-speed problems of the traditional design and shows that a redesigned rickshaw at about 55 kg with gears raises operator income ([ITDP, 2006](https://itdp.org/2006/07/01/rickshaws-in-the-new-millennium/)).
- **Bolted space-frame cargo bikes.** N55's XYZ Cargo bikes are built from standard aluminium tubes joined with stainless bolts and no welding, published under CC BY-NC-SA 4.0 ([N55](https://www.n55.dk/MANUALS/SPACEFRAMEVEHICLES/XYZCARGO.html)). They prove a bolt-together cargo cycle can carry real loads for years, but the license bars commercial use without a partnership, and tube frames still need accurate cutting and drilling by hand.
- **Home-built bolted trikes.** An open write-up of a bolted aluminium utility trike, built with a hacksaw and drills, shows the approach works for a single maker carrying 45 kg or more ([AprilWick](https://kg6gfq.gitlab.io/bolted-aluminum-utility-trike.html)).
- **Sheet metal bicycle frames.** Ronin Bicycle Works folded laser-cut 0.6 mm aluminium sheet into a riveted frame under 1.4 kg with no welding ([New Atlas](https://newatlas.com/ronin-folded-sheet-metal-bicycles/22120/)). It shows that cut sheet can make a stiff frame, but needs folding and a skilled builder.
- **Rugged utility bicycles.** World Bicycle Relief's Buffalo bicycle is designed for rural loads with a 100 kg carrier rating, local assembly and a mechanic training program ([World Bicycle Relief](https://worldbicyclerelief.org/the-bike/)). It is the model for FlatTrike's repair and training approach.

No open, commercially usable cargo tricycle cut entirely from flat plate was found in this search. That is the niche FlatTrike targets; a wider search is part of TRL 3.

## Open questions

- Which partner organization and which city first (for example a vendor union, a livelihood NGO or a university engineering department)? By the portfolio rule decided on 2026-09-25, co-design partners are picked per area later. Selection rule decided 2026-10-02: a city with dense goods delivery on narrow streets, a laser-cutting shop and a bicycle parts market; first candidate type to approach, a cycle-rickshaw or cargo-bike programme such as those ITDP has documented in South Asia.
- The layout is decided as a front loader (FTK-DDR-001). Do vendors in the partner city accept a front loader rather than the common rear-loading *thela*? This must be checked in co-design before the design is frozen.
- What payload do users actually carry, including routine overloading, and what is the steepest regular grade on their routes? The cargo rating now depends on the rider's weight (148 kg up to 80 kg, 138 kg up to 90 kg); co-design must check that vendors can work with that.
- Can laser shops in the target city cut 3 mm plate to the needed tolerance at the assumed price?
- Can the $300 production target (FTK-REQ-001 R18) be reached with wholesale bicycle parts? FTK-CAL-001 v0.2 estimates about $456 per trike at 100 units with Ackermann steering.

## User research and co-design

This design is for communities the author is not part of, so requirements come from the people who will use it.

- [ ] Identify a local partner organization (vendor union, NGO, cooperative or university)
- [ ] Run co-design sessions with vendors and delivery riders; record who, where and what was learned
- [ ] Visit a laser shop and a bicycle market in the target city; confirm stock, tolerances and prices
- [ ] Validate load, distance, terrain, parking and cost assumptions in the field
- [ ] Revise requirements (REQ) from findings before freezing the design

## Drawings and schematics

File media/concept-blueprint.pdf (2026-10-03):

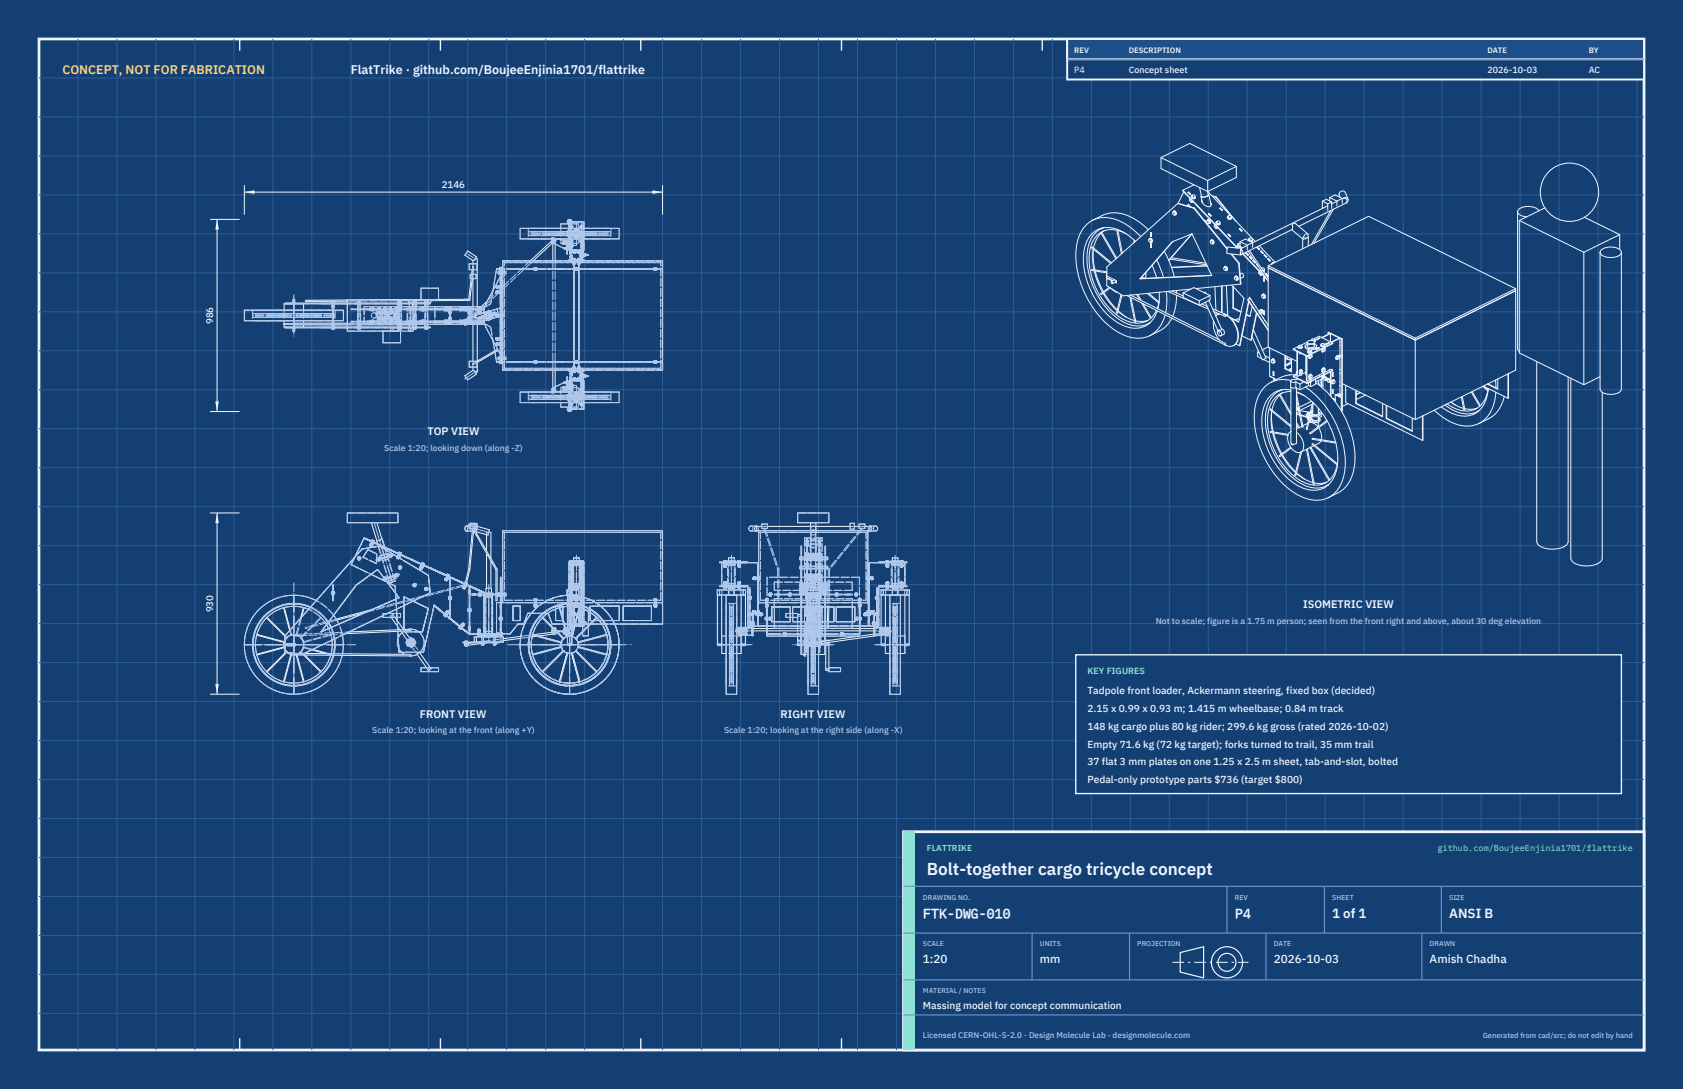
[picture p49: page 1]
CONCEPT, NOT FOR FABRICATION; FlatTrike · github.com/BoujeeEnjinia1701/flattrike; FRONT VIEW; TOP VIEW; RIGHT VIEW; ISOMETRIC VIEW; REV; DESCRIPTION; DATE; Concept sheet; FLATTRIKE; github.com/BoujeeEnjinia1701/flattrike; DRAWING NO. FTK-DWG-010; REV P4; SHEET 1 of 1; SIZE ANSI B; SCALE 1:20; UNITS mm; PROJECTION; DRAWN Amish Chadha; Licensed CERN-OHL-S-2.0 · Design Molecule Lab · designmolecule.com; Generated from cad/src; do not edit by hand

Scale 1:20; looking down (along -Z)

Not to scale; figure is a 1.75 m person; seen from the front right and above, about 30 deg elevation

KEY FIGURES
Tadpole front loader, Ackermann steering, fixed box (decided)
2.15 x 0.99 x 0.93 m; 1.415 m wheelbase; 0.84 m track
148 kg cargo plus 80 kg rider; 299.6 kg gross (rated 2026-10-02)
Empty 71.6 kg (72 kg target); forks turned to trail, 35 mm trail
37 flat 3 mm plates on one 1.25 x 2.5 m sheet, tab-and-slot, bolted
Pedal-only prototype parts $736 (target $800)

Scale 1:20; looking at the front (along +Y)

Scale 1:20; looking at the right side (along -X)

Bolt-together cargo tricycle concept

MATERIAL / NOTES
Massing model for concept communication

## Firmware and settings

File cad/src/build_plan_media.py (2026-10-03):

"""FlatTrike prototype build plan pictures (FTK-BLD-001, STANDARDS section 18).

Run from the repo root:  python cad/src/build_plan_media.py [overview|sheets|joints|steps ...] [only=N,N]
With no argument it draws everything. Every picture is drawn from cad/src/model.py
(build_components), so the pictures and the model never disagree:
    docs/05-build-plan/overview.png        every component pulled apart, numbered in build order
    cad/drawings/FTK-DWG-101 to 124        making sketches for the made, cut and drilled components
    docs/05-build-plan/joint-NN.png        close-ups of the joints that need explaining
    docs/05-build-plan/step-NN.png         one picture per assembly step
Uses .kit/build_views.py. BUILD PLAN ILLUSTRATION, PLAN NOT YET BUILT.
"""
import math
import sys
from pathlib import Path

ROOT = Path(__file__).resolve().parents[2]
sys.path[:0] = [str(ROOT / ".kit"), str(ROOT / "cad" / "src")]
import build_views as bv  # noqa: E402
from build_views import Part  # noqa: E402
import model as M  # noqa: E402

import numpy as np  # noqa: E402
from scipy import ndimage  # noqa: E402

# ------------------------------------------------- leader lines that end on a part you can see
# The kit puts a leader on a vertex of the part, which can be hidden behind a nearer part. This
# script wraps the kit's rasterizer to draw a second, flat "which part is here" image, then ends
# each leader on a visible pixel of its own part, as near as possible to the kit's choice and
# well inside the part's visible area.
_raster_kit = bv._raster
_VIS = {}
_BADGE_BESIDE_SMALL = False


class _Px(np.ndarray):
    pass


def _raster_visible(items, elev, azim, W, H, ss=2):
    img, proj, verts = _raster_kit(items, elev, azim, W, H, ss)
    tris, cols, ids = [], [], []
    for k, (p, color, alpha, off) in enumerate(items):
        v, t = bv._tris(p.shape)
        tri = (v + np.asarray(off, float))[t]
        tris.append(tri); cols.append(np.zeros((len(tri), 4))); ids.append(np.full(len(tri), k))
    _, _, _, idb = bv._zbuffer(np.vstack(tris), np.vstack(cols), elev, azim, W, H, ids=np.concatenate(ids))
    _VIS.clear()
    free = None
    for k, v in enumerate(verts):
        m = idb == k
        if not m.any():
            continue
        x0, y0 = proj(bv._anchor_kit(v))
        inner = ndimage.distance_transform_edt(m)
        best = inner >= min(4.0, inner.max())             # at least 4 px inside the part where it can be
        ys, xs = np.nonzero(best)
        j = np.argmin((xs - x0) ** 2 + (ys - y0) ** 2)
        px_, py_ = xs[j] + 0.5, ys[j] + 0.5
        if _BADGE_BESIDE_SMALL and m.sum() < 1500:      # overview key: a numbered badge would hide a small part,
            if free is None:                              # so it sits in clear space right beside the part instead
                free = ndimage.distance_transform_edt(idb < 0) >= 14
            fy, fx = np.nonzero(free)
            jj = np.argmin((fx - px_) ** 2 + (fy - py_) ** 2)
            px_, py_ = fx[jj] + 0.5, fy[jj] + 0.5
        _VIS[id(v)] = (px_, py_)

    def proj_visible(pts):
        if isinstance(pts, _Px):
            return np.asarray(pts)
        return proj(pts)
    return img, proj_visible, verts


def _anchor_visible(v):
    if id(v) in _VIS:
        return np.asarray(_VIS[id(v)], float).view(_Px)
    return bv._anchor_kit(v)


bv._anchor_kit = bv._anchor
bv._anchor = _anchor_visible
bv._raster = _raster_visible

P = M.P
OUT = ROOT / "docs" / "05-build-plan"
DWG = ROOT / "cad" / "drawings"
DATE = "2026-10-01"
C = M.build_components()

COL = {"spine": "#64748B", "cover": "#475569", "rib": "#D4A017", "saddle": "#B45309", "uyoke": "#0F766E",
       "lyoke": "#115E59", "ht": "#1F2937", "bb": "#7C3AED", "seat": "#9333EA", "stay": "#94A3B8", "bridge": "#CA8A04",
       "spacer": "#A16207", "bulk": "#334155", "rail": "#1D4ED8", "beam": "#2563EB", "post": "#0E7490",
       "cheek": "#155E75", "collar": "#0891B2", "column": "#374151", "drop": "#C2410C", "fork": "#27272A",
       "wheel": "#3F3F46", "arm": "#EA580C", "clamp": "#9A3412", "link": "#DC2626", "drive": "#6D28D9",
       "box": "#C08A4A", "bars": "#2563EB", "bolt": "#111827", "ghost": "#D1D5DB", "stop": "#B91C1C"}
REV2 = ("P2", "Steering lock stop added (decided 2026-10-02, FTK-DEC-001)", "2026-10-02", "AC")
REV_TRAIL = "forks turned to trail (FTK-DEC-001)"
P1 = ("P1", "Making sketch for the prototype build plan", "2026-10-01", "AC")


def S(*names):
    out = None
    for n in names:
        sh = C[n].shape
        out = sh if out is None else out + sh
    return out


def starts(*prefixes):
    return [n for n in C if any(n.startswith(p) for p in prefixes)]


def bolts(*groups):
    return [n for n in C if n.startswith("Bolt:") and any(n.startswith(f"Bolt: {g}") for g in groups)]


def part(name, shape, color, explode=(0, 0, 0), alpha=1.0):
    return Part(name, shape, color, None, tuple(explode), alpha)


def mv(p, e):
    return Part(p.name, p.shape, p.color, None, tuple(e), p.alpha)


SIDE = ("left", "right")


# ----------------------------------------------------------------- named groups, in build order
def groups():
    g = {}
    g["spine"] = part("Spine side plates (2)", S("Spine side plate, left", "Spine side plate, right"), COL["spine"])
    g["ribs"] = part("Spine ribs (2)", S("Spine rib at 800", "Spine rib at 900"), COL["rib"])
    g["saddles"] = part("Seat tube saddles (2)", S("Seat tube saddle, lower", "Seat tube saddle, upper"), COL["saddle"])
    g["uyoke"] = part("Upper yoke", C["Upper yoke"].shape, COL["uyoke"])
    g["topc"] = part("Spine top cover", C["Spine top cover"].shape, COL["cover"])
    g["botc"] = part("Spine bottom cover", C["Spine bottom cover"].shape, COL["cover"])
    g["lyoke"] = part("Lower yoke", C["Lower yoke"].shape, COL["lyoke"])
    g["ht"] = part("Central head tube and headset cups", S("Central head tube", "Central headset cups"), COL["ht"])
    g["bb"] = part("Bottom bracket shell and cups", C["Bottom bracket shell and cups"].shape, COL["bb"])
    g["seat"] = part("Seat tube and shaft collars", S("Seat tube", "Seat tube shaft collars"), COL["seat"])
    g["stays"] = part("Rear stay plates (2)", S("Rear stay plate, left", "Rear stay plate, right"), COL["stay"])
    g["bridge"] = part("Stay bridge", C["Stay bridge"].shape, COL["bridge"])
    g["nodes"] = part("Spacer washers, spacer tubes, node bolts", S(*starts("Spacer washer stacks", "Spacer tube", "Bolt: stay node")),
                      COL["spacer"])
    g["bulk"] = part("Bulkhead", C["Bulkhead"].shape, COL["bulk"])
    g["rails"] = part("Bed rails (2)", S("Bed rail, left", "Bed rail, right"), COL["rail"])
    g["beams"] = part("Axle beam plates (2)", S("Axle beam plate, rear", "Axle beam plate, front"), COL["beam"])
    g["posts"] = part("Knuckle posts: plates and cheeks (2 sets)", S(*starts("Knuckle post plate", "Knuckle post inner", "Knuckle post outer")),
                      COL["post"])
    g["stops"] = part("Steering lock stops (2)", S(*starts("Steering lock stop"), *bolts("Steering lock stop")), COL["stop"])
    g["collars"] = part("Knuckle collar plates, head tubes, cups", S(*starts("Knuckle collar plate", "Knuckle head tube", "Knuckle headset")),
                        COL["collar"])
    g["column"] = part("Steering column and drop arm", S("Steering column (cut-down fork and quill stem)", "Drop arm",
                                                          *bolts("drop arm")), COL["drop"])
    g["forks"] = part("Front forks and wheels (2)", S("Front fork, left", "Front fork, right", "Front wheel, left", "Front wheel, right"),
                      COL["fork"])
    g["arms"] = part("Steering arms, clamp plates, U-bolts (2)", S(*starts("Steering arm", "U-bolts", "Bolt: Steering arm")), COL["arm"])
    g["link"] = part("Tie rod and drag link", S("Tie rod with rod ends", "Drag link with rod ends", "Rod end bolts"), COL["link"])
    g["drive"] = part("Rear wheel and drivetrain", S("Rear wheel", "Drivetrain (chainring, cranks, pedals, chain, sprocket)"),
                      COL["drive"])
    g["box"] = part("Cargo box and lid", S("Cargo box", "Cargo box lid", *starts("Spacer washers, box"), *bolts("box", "Box")),
                    COL["box"])
    g["ride"] = part("Seatpost, saddle, handlebar (brakes not shown)", S("Seatpost and saddle", "Handlebar and stem"), COL["bars"])
    return g


ORDER = ["spine", "ribs", "saddles", "uyoke", "topc", "botc", "lyoke", "ht", "bb", "seat", "stays", "bridge", "nodes",
         "bulk", "rails", "beams", "posts", "stops", "collars", "column", "forks", "arms", "link", "drive", "box", "ride"]


# ----------------------------------------------------------------- overview
def overview():
    G = groups()
    off = {"spine": (0, 0, 0), "ribs": (0, 0, 330), "saddles": (-60, 0, 420), "uyoke": (100, 0, 420),
           "topc": (-40, 0, 620), "botc": (0, 0, -300), "lyoke": (100, 0, -420), "ht": (260, 0, -120),
           "bb": (-60, 0, -560), "seat": (-200, 0, 760), "stays": (-520, 0, 0), "bridge": (-700, 0, 420),
           "nodes": (-220, 0, -480), "bulk": (500, 0, 120), "rails": (700, 0, -60), "beams": (900, 0, -380),
           "posts": (950, 0, 230), "stops": (1300, 0, 120), "collars": (1050, 0, 560), "column": (300, 380, -520), "forks": (1350, 0, -520),
           "arms": (1250, 0, -950), "link": (750, 0, -820), "drive": (-850, 0, -520), "box": (800, 0, 900),
           "ride": (150, 0, 1150)}
    parts = []
    for k in ORDER:
        p = G[k]; p.explode = off[k]; parts.append(p)
    global _BADGE_BESIDE_SMALL
    _BADGE_BESIDE_SMALL = True
    return bv.overview(parts, OUT / "overview.png", "FlatTrike prototype: every component, pulled apart",
                       subtitle="Numbered in build order. Seen from the front right and above. The bolts that join the plates are not shown",
                       elev=16, azim=-62, size=(13, 8.5), dpi=150, key=True)


# ----------------------------------------------------------------- making sketches
def flat(shape, origin, x_dir, z_dir):
    import build123d as b
    return b.Plane(origin=origin, x_dir=x_dir, z_dir=z_dir).to_local_coords(shape)


def turn(shape):
    """A transverse (YZ) plate turned so its face shows in the front view."""
    import build123d as b
    return b.Rot(0, 0, -90) * shape


def joint_text(name):
    """Count the tabs, slots, bolt holes and T-slots on a plate from the model's joint list."""
    tabs = sum(j["tabs"] for j in M.JOINTS if j["edge"] == name)
    tslots = sum(j["bolts"] for j in M.JOINTS if j["edge"] == name and j["kind"] != "through")
    slots = sum(j["tabs"] for j in M.JOINTS if j["face"] == name)
    holes = sum(j["bolts"] for j in M.JOINTS if j["face"] == name and j["kind"] != "through")
    return tabs, tslots, slots, holes


def cutnote(name):
    tabs, tslots, slots, holes = joint_text(name)
    bits = []
    if tabs:
        bits.append(f"{tabs} tabs")
    if tslots:
        bits.append(f"{tslots} T-slots")
    if slots:
        bits.append(f"{slots} slots")
    if holes:
        bits.append(f"{holes} bolt holes 9 mm")
    return ", ".join(bits)


TSLOT = "T-slot: 9 mm wide, 23 deep, with a 13.6 x 8.4 mm window 10 mm in for the nut."
CUT = "Laser or waterjet cut from 3 mm S235JR or A36 steel, from the model's outline."
MAT = "3 mm S235JR or A36 steel plate, laser or waterjet cut"


def sheets(only=None):
    import build123d as b
    G = groups()
    base = dict(project="FlatTrike", date=DATE)
    out = []
    ghost = lambda *ks: [G[k] for k in ks]  # noqa: E731

    def others(exclude, *prefixes):
        """Grey neighbours: every component starting with a prefix, except the part itself."""
        return [Part(n, C[n].shape, COL["ghost"]) for n in C if n != exclude and any(n.startswith(p) for p in prefixes)]
    tdir, wdir = M.seat_axes()

    def sheet(no, *a, **k):
        if only and no not in only:
            return
        out.append(bv.component_sheet(*a, dwg_no=f"FTK-DWG-{no}", **{**base, **k}))
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

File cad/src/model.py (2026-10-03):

"""FlatTrike parametric model (build123d), TRL 3, constructable design (FTK-DDR-003).

Run from the repo root:
    python cad/src/model.py            exports STEP and STL into cad/step and cad/stl and prints the plate schedule
    python cad/src/model.py --check    runs the constructability checks (joints, overlaps, contacts, steering sweep,
                                       running clearances, lock stops, trail and scrub measured on the model)

Every physical piece is its own solid in build_components(): each cut plate (left and right
separately), each bought part and each bolt set. build_parts() fuses them by BOM line for the
calculations, the concept media and the general arrangement. The build plan pictures
(cad/src/build_plan_media.py) draw from build_components(), so pictures and model agree.

Coordinates in mm. X forward, Y to the left (as the rider sits), Z up, ground at Z = 0, rear axle at X = 0.
Layout (decided by Amish, 2026-09-25, FTK-DDR-001): tadpole front loader. Steering (FTK-DDR-002 item 13):
Ackermann steering with a fixed box. Every steel frame part is a flat 3 mm plate cut from DXF; nothing
is welded or bent.

How the pieces join (FTK-DDR-003, design for construction):
  * Tee joints: tabs on the edge of one plate sit in slots cut in the other and carry the load; between
    tabs an M8 bolt passes through the face plate into a T-slot in the edge plate, where an all-metal
    locknut sits in a window and cannot turn. Where the edge plate meets the face plate at its edge (the
    spine covers, the knuckle post corners) the slot is an open notch: a finger joint.
  * Parallel plates (stays outside the spine): through-bolts with stacks of cut spacer washers outside
    the spine and a cut steel spacer tube inside it.
  * Rails and axle beams cross in halving joints (slot from below in the rail, from above in the beam).
  * Head tubes and the bottom bracket shell are clamped between two plates by their own pressed or
    threaded cups: each cup's spigot passes through a hole in the plate and its flange holds the plate
    against the end of the tube or shell.
  * Each knuckle fork is fitted turned round, so its legs and axle trail the vertical knuckle head tube by
    the fork offset: 35 mm of mechanical trail, no caster (decided by Amish, 2026-10-03).
  * Steering arms clamp to the inboard fork leg with two U-bolts through a clamp plate; the drop arm
    is a plate slid over the two leg stubs of a cut-down steering fork, held by shaft collars.
PRELIMINARY, NOT FOR FABRICATION.
"""
from __future__ import annotations

import math
import sys
from dataclasses import dataclass, field
from pathlib import Path

from build123d import (Box, Compound, Cylinder, Face, Plane, Pos, Rot, Solid, Vector, Wire,
                       export_step, export_stl, extrude)

# ---------------- parameters (mm); edit these, not the geometry below ----------------
PARAMS = {
    "T": 3.0,                 # plate thickness, S235JR or A36 class
    "WHEEL_R": 254.0,         # 20 x 2.125 in tyre (ISO 406), outer radius
    "TYRE_W": 54.0,           # tyre section width
    "WB": 1450.0,             # front steering (kingpin) axes ahead of the rear axle; the front axles trail them
                              # by FORK_OFFSET, so the wheelbase is WB - FORK_OFFSET (see axle_x())
    "TRACK": 840.0,           # front wheel centre to centre
    "KP_X": 1000.0,           # central steering axis, ahead of the rear axle
    "HT_Z0": 310.0,           # central head tube bottom (top face of the lower yoke)
    "HT_LEN": 200.0,          # central head tube length = gap between the yokes (FTK-DDR-002 item 19)
    "HT_OD": 40.0,            # head tube outside diameter, 1 1/8 in threaded headset
    "CUP_HOLE_R": 17.25,      # plate hole for a headset cup spigot (34 mm press fit)
    "SPINE_IN": 30.0,         # inner face of each spine side plate from the centre plane
    "STAY_IN": 60.0,          # inner face of each rear stay plate (120 mm hub OLD)
    "BB_X": 600.0,            # bottom bracket centre
    "BB_Z": 265.0,
    "BB_HOLE_R": 17.75,       # spine hole for the bottom bracket cup spigots (BSA 1.37 in thread)
    "SEAT_ANGLE": 73.0,       # seat tube angle, degrees from horizontal
    "SADDLE_TOP": 930.0,      # saddle top height
    "SEAT_TUBE_R": 15.9,      # bought seat tube, 31.8 x 2.3 mm (27.2 mm seatpost)
    "SADDLE_Z": (600.0, 700.0),   # seat line heights of the lower and upper seat tube saddles
    "CHAINLINE": -44.0,       # chain plane, right-hand drive (negative Y is the rider's right)
    "RING_T": 32,             # chainring teeth
    "SPROCKET_T": 24,         # rear sprocket teeth
    "CRANK": 170.0,
    "FORK_OLD": 100.0,        # bought 20 in fork, front hub over locknuts
    # fork direction (decided by Amish 2026-10-03, FTK-DEC-001): each knuckle fork is a 20 in fork whose legs run
    # parallel to its steerer, set FORK_OFFSET off it (BMX-type crown offset), fitted turned round so the legs and
    # axle trail the vertical knuckle head tube. Caster stays 0; mechanical trail = FORK_OFFSET.
    "FORK_OFFSET": 35.0,      # leg and axle offset behind the steering axis (buy 30 to 40 mm)
    "TRAIL_RANGE": (30.0, 70.0),  # mechanical trail allowed by the constructability check, mm
    "LEG_R": 11.0,            # fork leg radius
    "LEG_Y": 61.0,            # fork leg centre from the wheel centre plane
    "POST_Y0": 283.0,         # knuckle post inner face from the centre plane
    "POST_W": 45.0,           # knuckle post box width (inner to outer cheek)
    "POST_X": 25.0,           # knuckle post transverse plates' inner faces at WB +/- this
    "POST_LIP": 8.0,          # knuckle post plates' lower part past the outer cheek (10 mm before the trailing fork crown)
    "KN_Z0": 555.0,           # knuckle head tube bottom (top face of the lower collar plate)
    "KN_LEN": 120.0,          # knuckle head tube length = gap between the collar plates
    "ARM_L": 120.0,           # Ackermann steering arm, kingpin axis to tie rod joint
    "ARM_Z": 321.0,           # steering arm plate underside, below the knuckle post column
    "CLAMP_Z": (303.0, 343.0),    # steering arm clamp plate, bottom and top
    "UBOLT_Z": (310.0, 336.0),    # U-bolts round the inboard fork leg
    "AB_Z0": 350.0,           # bottom of the axle beams and knuckle post columns (steering arms pass beneath)
    "COVER_HW": 45.0,         # half width of the spine covers and the lower yoke tongue (12 mm past the side plates)
    "DROP_Z": 264.0,          # drop arm plate underside (it is bolted under the steering fork crown)
    "CROWN_BOLT_R": 32.0,     # drop arm bolts through the crown, either side of the steering axis
    # drop arm: same length and direction as the left steering arm, so the column, drop arm, drag link and
    # left steering arm form a parallelogram and the left wheel turns with the handlebar (FTK-DDR-003)
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

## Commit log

2026-09-24 Initial scaffold: standard open hardware layout, CERN-OHL-S v2 + MIT licenses
    Claude-Session: https://claude.ai/code/session_01XuhhSU4W6fYhgCfURbrkut
    [bom.csv]
2026-09-25 Adopt portfolio kit v1.3.0: session commands, scale figure, 3D viewer, flow diagrams
    Adds .claude/commands (/populate, /advance-trl3, /rein-in, /refresh-media)
    so every Claude Code session starts from the standard prompts, and extends
    concept media with a 1.75 m scale figure, an interactive glTF viewer and
    system or energy flow diagrams. TRL cap 3 unchanged.
    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
2026-09-25 Kit v1.3.1: renderer fixes from the TremorTrace pilot
    Context scale parts for small objects, cutaway exclusions, and text
    labels in flow diagrams.
    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
2026-09-25 Populate flattrike to a strong TRL 2 with concept media (batch 3)
    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
    [bom.csv]
2026-09-25 Advance flattrike to TRL 3 (batch 3)
    Decisions approved by Amish 2026-09-25 recorded in DDR-001. TRL 4 is on hold.
    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
    [bom.csv, flattrike-assembly.step, flattrike-assembly.stl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]
2026-09-26 Accept all recommendations (DDR-002), switch footer to designmolecule.com, add README write-up with new inspiration point
    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
    [bom.csv, flattrike-assembly.step, flattrike-assembly.stl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]
2026-09-27 Product appearance model and photoreal renders
    Adds cad/src/product_model.py (appearance model for renders only, all main
    dimensions from model.py) and Blender renders in media/render-*.png,
    captioned with the project, repository and viewing direction. README leads
    with the product render; trl stays 3.
    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
2026-10-01 Image quality pass: legible exploded views, flow diagrams and drawing sheets
    Kit 1.6.1 image layout: the parts list sits in its own column, number bubbles sit on visible parts and never overlap, small parts get a leader, pictures are cropped to the subject, flow labels keep numbers with their units, and sheet captions and the revision table no longer overprint. Concept images, blueprint and general arrangement sheet regenerated; repo-specific labels moved clear of other text and lines.
2026-10-01 Kit 1.7.0: constructable design, illustrated build plan and design decisions register
    The design is now constructable: every part can be made and fits its neighbours, with each change recorded in a Design for construction decision record (made under Amish's 2026-09-30 instruction; ope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
    [bom.csv, flattrike-assembly.step, flattrike-assembly.stl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]
2026-10-02 Record Amish's approval of the open-decision recommendations
    Amish approved the recommendation on every open decision in the design decisions register ("i approve your recommendations for all 555 open decisions.", 2026-10-02). Each decision is moved to Decisio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
2026-10-03 Carry approved follow-ups into the design and redo photoreal renders
    Amish approved the follow-up actions from the open-decision sign-off ("APPROVED CHANGES, COMPLETE THESE", 2026-10-02), the design-for-construction change tables in ten repos, the last wave's open dec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
    [bom.csv, flattrike-assembly.step, flattrike-assembly.stl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]
2026-10-03 Record Amish's 2026-10-03 decisions; FlatTrike fork and PotPress guard fixes
    Amish, 2026-10-03: "PalletPilot - i accept it"; "FlatTrike - i accept your design recommendation, proceed and execute the solution for fork direction or caster"; "PotPress - move forward with the four guard fixes. I accept the cost."; "GravitySort - i accept your recommendation"; "TIght Margins - i accept the margins"; "Cost over target - i accept all the cost variations and overruns". FlatTrike knuckle forks turned to trail (35 mm trail); PotPress finer mesh, small-hole plates, top beam and crank bracket covers, ISO 13857 desk check now met on paper. Registers, requirements, drawings, pictures, renders and PDFs upd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
    [bom.csv, flattrike-assembly.step, flattrike-assembly.stl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]

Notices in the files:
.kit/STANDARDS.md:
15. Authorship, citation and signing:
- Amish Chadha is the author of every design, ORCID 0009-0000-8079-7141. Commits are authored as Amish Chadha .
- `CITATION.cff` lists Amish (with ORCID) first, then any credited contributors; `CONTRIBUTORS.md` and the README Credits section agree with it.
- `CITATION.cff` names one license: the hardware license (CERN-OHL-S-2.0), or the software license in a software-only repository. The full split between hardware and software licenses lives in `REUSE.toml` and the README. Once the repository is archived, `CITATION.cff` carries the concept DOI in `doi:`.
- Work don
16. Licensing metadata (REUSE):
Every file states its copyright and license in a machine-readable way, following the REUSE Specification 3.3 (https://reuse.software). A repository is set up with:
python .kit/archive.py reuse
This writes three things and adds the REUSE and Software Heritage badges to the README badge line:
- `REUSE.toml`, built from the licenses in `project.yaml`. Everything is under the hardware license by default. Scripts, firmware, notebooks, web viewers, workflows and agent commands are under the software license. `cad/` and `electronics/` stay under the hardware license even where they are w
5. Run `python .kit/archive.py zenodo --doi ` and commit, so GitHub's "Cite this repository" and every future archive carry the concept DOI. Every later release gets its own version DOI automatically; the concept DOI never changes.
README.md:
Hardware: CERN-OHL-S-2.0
